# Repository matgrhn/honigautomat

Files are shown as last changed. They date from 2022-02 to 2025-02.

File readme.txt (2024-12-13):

what do you have to check and configure in the arduino sketch:

Please check & update before you upload the sketch to your arduino.
youtube channel containing a set of videos about this vendor machine:
https://youtube.com/playlist?list=PLrYKRosgwf_19UN1uPkxFnaKNIluaASAk

#********************************************************************************#
are you interested in cashless payment (credit card or apple pay etc.) or 
in payment with bill (Zahlung mit Geldscheinen)? Please send a mail.
honigautmat@gmx.de
#********************************************************************************#

#################################################################################
Depending on selected board (e.g. UNO or Mega 2560) and number of buttons=selector and compartments the pin definition must be adapted as follows.
Please ensure that the cable connectors are established accordingly.
//uno
//const int selector[5] = {17, 16, 15, 14, 0 }; // input pins for selector buttons (A0=14, A1=15, A2=16, A3=17, Dig0=0) UNO
// when you want to user 2 * 5 compartments with UNO it is not possible to have power-off features at the same time because of lack of pins. In this case I suggest
// to run 1 row with 5 and one row with 4 compartements; use the free PIN to steer the power off relais; as an alternative you can consider to use PIN 1 (which is not recommended because of issues with serial-IOs); this may be possible 
// if you set all lines dealing with "Serial..." to "// serial..."
//mega
//const int selector[15] = {A1, A2, A3, A4, A5, A6, A7, A8, A9, A10, A11, A12, A13, A14, A15}; // input pins for selector buttons MEGA
const int selector[5] = {A1, A2, A3, A4, A5}; // input pins for selector buttons MEGA 5 buttons and 5/10 or 15 boxes

for Uno with 5 compartments you can use more features than  having 10 compartments; 
to activate search for "refillbutton", "homematic" and "poweroff"; remove "//" in these areas

##################################################################################
Following row defines the price for each compartment. In this example it is 5€; Having 5 Buttons at the vendor machine even with 10 or 15 compartments the number of price is fix: 5
In dieser Zeile kann man vorgeben, welcher Preis für die Fächer vorbelegt werden soll (in diesem Beispiel 5€; es müssen immmer 5 Werte sein, auch wenn man 10 Fächer hat):

int conveyorPrice[5] = {500, 500, 500, 500, 500}; // default 500ct (eeprom currently not used)

How many compartments/rows are available?
Wieviele Fächer je Reihe werden angeschlossen? 

bei 5 Fächern / 5 compartments:
int conveyorItems[5] = {1, 1, 1, 1, 1};
const int maxrow = 1;
const int max = 5; 
int conveyorPrice[5] = {500, 500, 500, 500, 500}; // default value in ct

bei 10 Fächern / 10 compartments:
int conveyorItems[5] = {2, 2, 2, 2, 2};
const int maxrow = 2;
const int max = 5; 
int conveyorPrice[5] = {500, 500, 500, 500, 500}; // default value in ct

bei 15 Fächern / 15 compartments:
int conveyorItems[5] = {3, 3, 3, 3, 3};
const int maxrow = 3;
const int max = 5; 
int conveyorPrice[5] = {500, 500, 500, 500, 500}; // default value in ct

If you want to run the system with a button for each compartment number of rows should be set to 1
##################################################################################
release 3

please consider that for UNO the pin assignment is now different than before!
**********************************************************************************
new feature with release 3 - for UNO 
check temperature with help of DS18B20 and turn cooling on/off 
the usage is recommended in summer time (this feauture is on and power-save disabled when you connect pin "summer_pin" to GND).
for winter disconnect this again.

Temperature sensor DS18B20
RED +5V
BLACK GND (5V)
YELLOW connect to pin "tempsensor" and via 4.7k ohm resistor with +5V

##################################################################################
NV10 - payment with bill now available for Mega 2560

DIPs on NV10:
1 LOW
2 HIGH (this has been changed recently!)
3 LOW
4 HIGH

DIP2 on HIGH to get 4 pulses instead of 1 because in some installations compartment opening impacted the pulse interrupt. Now all pulses less 4 are ignored.

please note that electronic payment with Najax Onyx is not yet ready but dev started! (beta)

int nv10_act = 13;
connect this pin to GND to activate feature

int nv10_ch1 = 9;   
int nv10_ch2 = 10;
connect to PIN 5 + 6 of NV10 to allow 5€ / 10€ (steering via sketch)

NV10 PINs:
1 connect to interrupt pin (arduino) and via 10kOhm to +5V
5 see above
6 see above
15 +12V (better turn on/off via coin acceptor relais "coin power") 
16 GND 12V

##################################################################################
new feature with release 2 - powersave:
after reaching idlePeriod relais "poweroffrelais" cuts the power; wakeup with poweron button (you need a separate self holding relais to keep power). See fritzing-documentation
This feature is active if powersave is set = 1 (otherwhise 0);
##################################################################################
new feature with release 2 - write/read eeprom
current price and remaining products in compartments per button-column will be stored in eeprom and is available after system restart. 
existing credit is deleted when restarting system
To force an eeprom update in case of new structure (e.g. additional set compartments to be activated)
##################################################################################
new feature with release 2 - reset credit after cutofftime = idle threshold
remaining credit will be deleted after a while
##################################################################################
new feature with release 3 - Jan 2023:
it is possible to disable the coin acceptor when all products are sold out
(mega only): connect PIN 17 with a free relais and lead power +12 for coin acceptor
through this relais (function not yet visible in fritzing drawing)

NV10 - bill acceptor now supported / der Geldscheinleser NV10 wird jetzt unterstützt

Payment cashless with Nayax Onyx (you need additional hardware and a contract with
Nayax for reconciliation/bank accounting; monthly fee & percentage to be paid.
Zahlung per Kreditkarte mit Nayax Onyx (in Testphase) wird jetzt unterstützt. 
Dafür wird zusätzliche Hardware sowie ein Supportvertrag mit Nayax benötigt. Dafür
fallen (geringe) monatliche Gebühren sowie ein paar Prozente Abschlag bei Zahlung 
an. Bei Interesse bitte mit mir Kontakt aufnehmen.

#********************************************************************************#

new feature in Oct 2023:

Payment with Nayax Onyx possible now. Please consider that because of the long boot time
of Onyx powersave must be disabled. 
How to wire: +12V, GND, Pulse 1, don't forget to pullup this to +5v;
To use Onyx you need beside the hardware (Onyx and Pulse-cable) an contract with Nayax for
credit card / payment clearing; this leads to an monthly fee and a percentage disagio for each
payment.
#********************************************************************************#

new feature in April 2024:
It is now possible to send & receive SMS-messages. 
You can receive messages about sold items or empty system. You can send messages to
change the threshold for this. You can send messages to load money onto the system and
finally it can be used for paypal-payments (QR-code or your paypal-account should be
visible for the client).
How does it work?
Deactivate the PIN of your simcard. I wasn't able to work with SMS using an IOT-Sim 
because my mobile phone provider doesn't deliver SMS from SIMs with international
phone number (not start e.g. with 49 for germany).
The automat sends a sms when automat is empty (threshold=0), 3 or less remaining 
(threshold=3) or for any sold item (threshold=99). You can send an SMS to your
system e.g. threshold=0 when you want to change the behaviour until the system is restarted.
Then the parameter which is set in the sketch is active again. 

!! don't use the powersupport from ardunino for the sim800L, it consumes too much power!!
Use a separate LM2596 and set this to 3,6V to supply SIM800L (never more than 4,2V)!!

It is now possible to pay with paypal. You have to avtivate "info via mail (html)" on paypal.com
website to receive an email about any received payment. With your email provider
you have to setup SMS-info towards your sim. Then the arduino will indentify how much
money was send and loads it onto the system. The value is visible on the display. It is 
possible to mix cash with paypal if the client wants it.
Preconfigered is any value to be loaded onto the system. Inform you clients
that Paypal-Payments need up to 30 seconds. You can create a QR-Code with a specific
amount of money using your paypal-app. During testing don't cancel your test sendings, because
Paypal blocked my first account and was not willing to reactivate. 
All activities are on your own risk!
Additional benefit: you can load money as well onto the system with sending an SMS containing 
the phrase "Sie haben x,00 EUR erhalten" in case of client is calling you because of 
whatever reason and you may want to give a free product or discount.
Because of this feature you should keep the phone number of your system confidentual.
#*********************************************************************************
Update 11.04.2024:
Nayax Onyx can now be inform about cash payments. I decided not to send the amount of
money by sending a number of pulses back but to send only one pulse (shown in 
nayax app as 1 EUR because number of empty compartments is more important than the
revenue. In configuration (nayax app or my.nayax.com in area "Pulse" set "Pulse IN1 Counter to 1" 
to allow your Nayax Onyx device to receive infos about cash payments. Please be patient, 
it needs some time until the cash payment is visible in you nayax app.
Special case: if a client combines Onyx and cash the last payment done will be used
to decide of a sold item will be reported as cash or not.
 
In addition you can now send "refill" via sms to the machine to activate the refill
routine wihtout opening the machine: all compartments which are registered as empty
will open and counters are set back to value written in the code.

If you have some of the additional hardware components e.g. NV10, Onyx, Sim800L please
use power supply with 2A. 

Update 16.05.2024:
to get Paypal payments we need to receive a SMS containing some key information.
As far as I found out a private Paypal account can be configured at the paypal
website to send sms after receiving money, for a business account you need to set 
up sms info with your mail provider, e.g. gmx is supporting this (9ct costs per sms). 
In the youtube video I show both ways how to setup the paypal. 
The QR code (containing a specific sum) can be generated using the paypal app.

##################################################################################
new feature with release 3 May 2024
with help of ChatGPT I have added some code to support a keypad to select number of
compartment items instead of pushing buttons. This mean all functions depending on buttons
will now be supported by numbers of the keypad e.g. in programming mode
1 - less
2 - more
3 - next
4 - open compartment 
5 - refill
(open and refill only during 'number of items change' phase - not while amending the prices.
it is possible to press one or two number values leading to numbers 0-9 or above 10.
Numbers less or equal "max * maxrow" are accepted during product selection.

###################################################################################

-------------------------------------------------------------------------------
Update 22.06.2024:
SMS:
some SIM800L modules are requesting higher voltage for stable connections - you should increase voltage from 3.6V up to 4.1v (MAX!!) 

Paypal:
depending on Paypal-account, private users can receive SMS directly, business accounts are receiving emails which have to be forwarded by your mail provider as sms.
SMS text contained for me always two spaces in front of text "EUR", but others (e.g. a friend in Austria) are receiving sms containing only one space " EUR". This is now considered in latest sketch (June 2024).
-------------------------------------------------------------------------------
Update 30.09.2024:
SMS/Paypal:
I was informed that Paypal recently changed the SMS message about payments (for private accounts, at least in Austria it was reported).
old text "... Sie haben 7,00 EUR erhalten" or "... Sie haben 7,00  EUR erhalten"  (one or two spaces before "EUR") to
new text "... Sie haben 7.0 EUR erhalten", which means new separator point instead of comma and only one digit after the separator. The sketch is now able to handle all three cases.
Update 0.10.2024:
In addition, the text "..EUR mit PayPal gesendet.." is now validated correctly.

--------------------------------------------------------------------------------
Update 10.10.2024:
Regarding Paypal: sim800l is required for this. Depending on your Paypal account, Paypal sends an SMS (to the number of the machine, which is therefore kept secret), or you receive an email, which you forward to the machine as an SMS via your email account. The Arduino evaluates the text and can then top up a sum. It can take up to 30 seconds for the SMS to arrive at the machine, which is due to Paypal or the email forwarding and not the Arduino.
Attention: Paypal has already blocked two of my accounts due to alleged fraudulent activities, which is why I no longer want to use Paypal. Technically, however, the concept is still supported. However, I now like to use top-up via SMS independently of Paypal by sending the machine an SMS with the appropriate text. One use case is when I get a call from a customer who is standing directly at the machine (coin doesn't work, no change, discount...)
--------------------------------------------------------------------------------
New from October 2024 (release 4):
Please don't use arduino Uno anymore, instead Mega 2560 ist suggested. The sketch is not updated for UNO any more!

Instead of the selection buttons, a keypad (3x4) can now be used. To do this,
keypad = true;
must be set, as well as maxrow=1; because each compartment has its own number with its own price. In programming mode, only prices are set, not product quantities. Input in cents, up to four digits. The price 9.99 is not possible for technical reasons. Every price change is concluded with #.
In programming mode, the compartment can be opened with *, but the counter is not changed. Therefore, always use the refill button when filling empty compartments. If necessary, press any compartments that have been opened incorrectly again afterwards. If prices are to be changed and the associated compartments are to be opened, programming mode must be run through for all compartments twice.
Either selection buttons OR keypad. Both at the same time are not supported.
Update 15.10.2024:
sms process changed. In case of threshold=3 (default or set per sms) the information about available remaining products is only send out in case of exact 3 remaining products and when empty.
Refill will not lead to send sms any more. Please note that threshold is set to value as defined in sketch during refill. 
--------------------------------------------------------------------------------
New from December 2024 
payment with QR-Code from Sumup is now possible!
You need sms feature (see video concerning sim800l / setup sim=true, sim of course, email account for each vending machine - I suggest gmx because it supports sms service [9ct per sms] with free mail account; create an sumup account, create an team member for each vending machine; setup team member and login with as this team member, create payment link , set permanent link = true and notify me about payments to true; generate QR code and add a text hint that it needs about one minute until the payment is displayed on the vending machine.
Login at gmx with specific mail account and create two filter rule: forward mails send from sumup and subject "Sie wurden bezahlt" - don't forget to set the "and"-condition to ensure that both filter rules are true - send sms. Done.
--------------------------------------------------------------------------------

any questions? pls contact me: mailto:honigautomat@gmx.de
Bei Fragen helfe ich gern weiter: honigautomat@gmx.de

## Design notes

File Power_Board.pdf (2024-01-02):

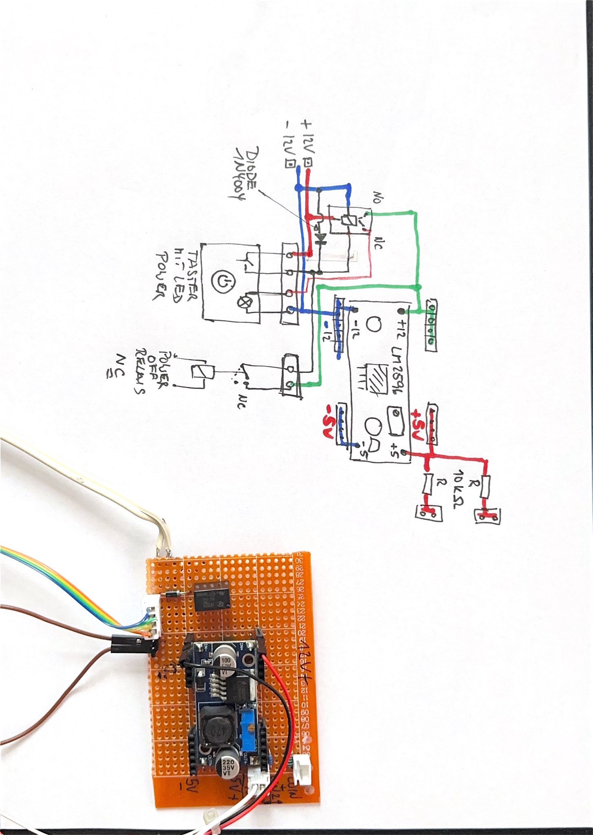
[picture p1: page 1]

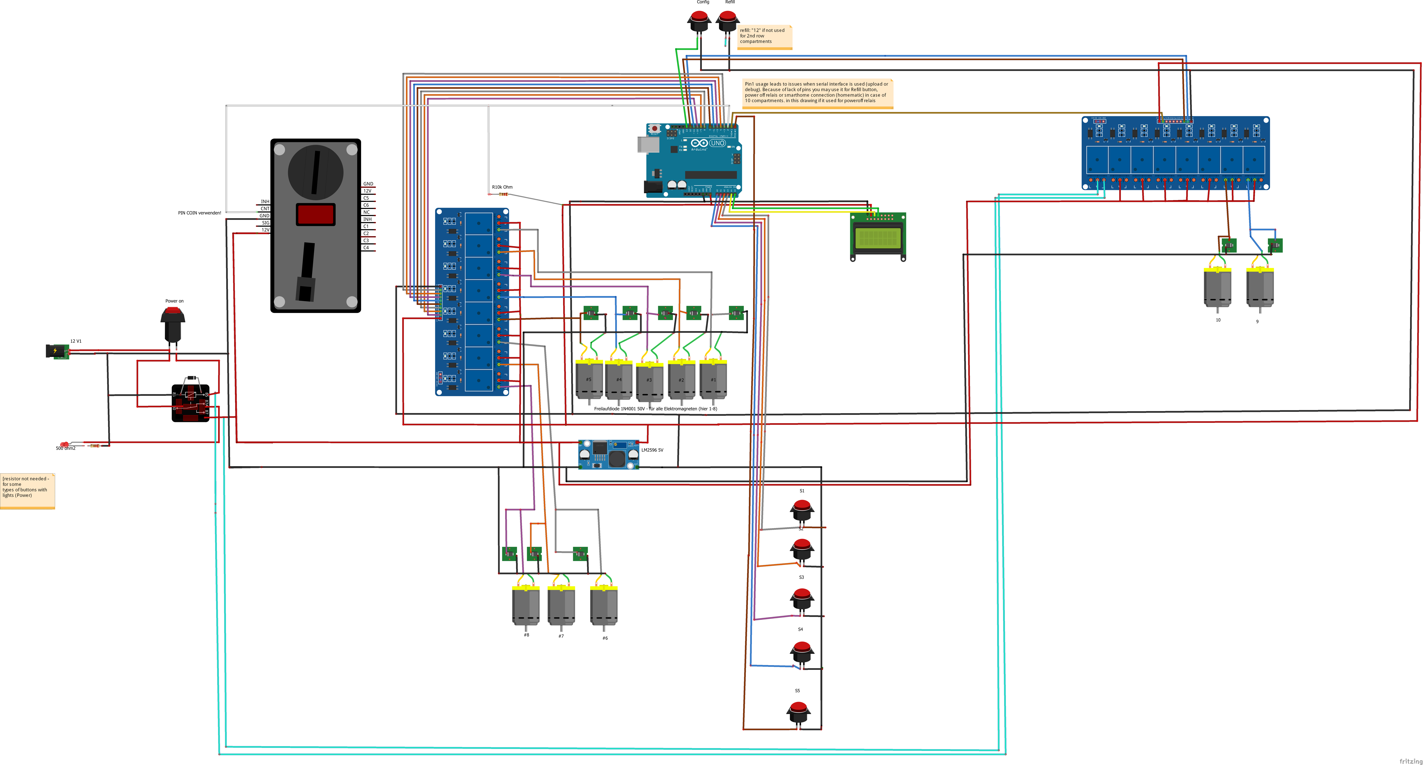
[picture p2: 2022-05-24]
Honigautomat_unoPowersave.png

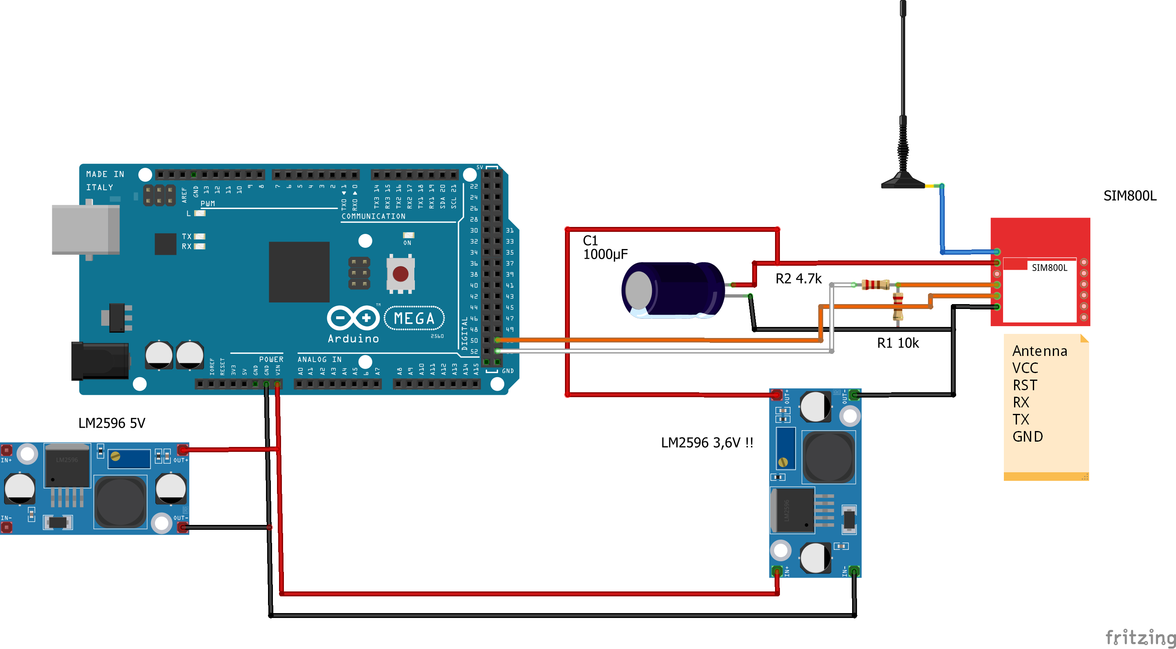
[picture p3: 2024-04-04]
Mega_SIM800l_SMS.png

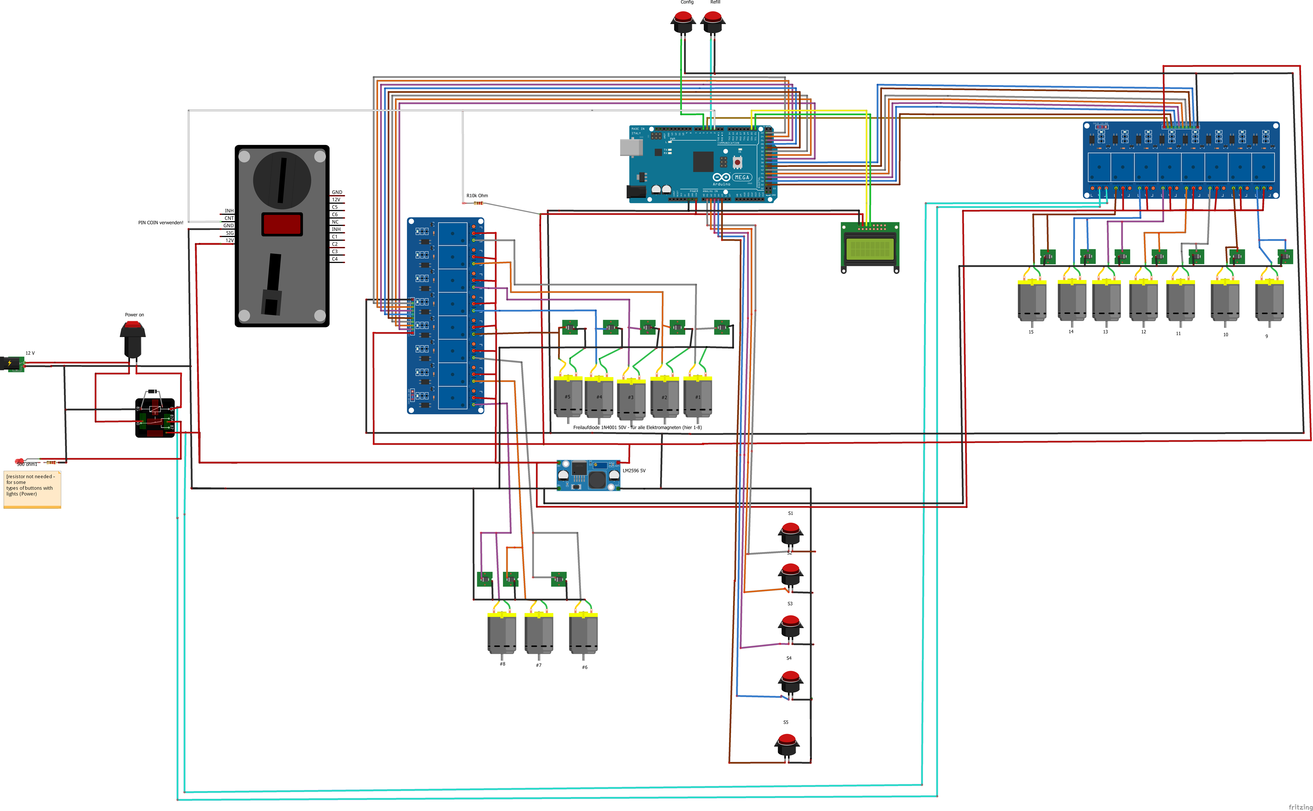
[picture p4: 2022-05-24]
Honigautomat_megaPowersave.png

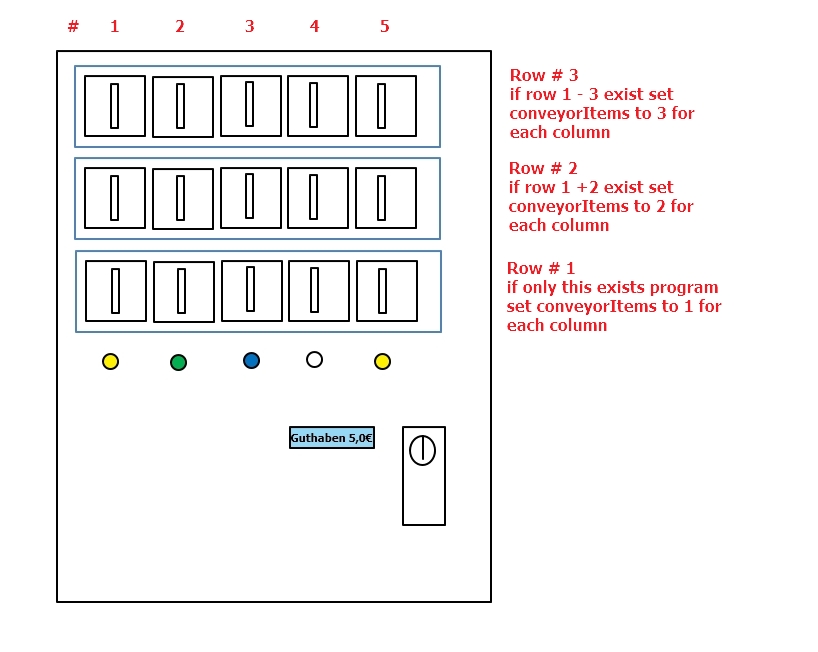
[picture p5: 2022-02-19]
vendor.jpg

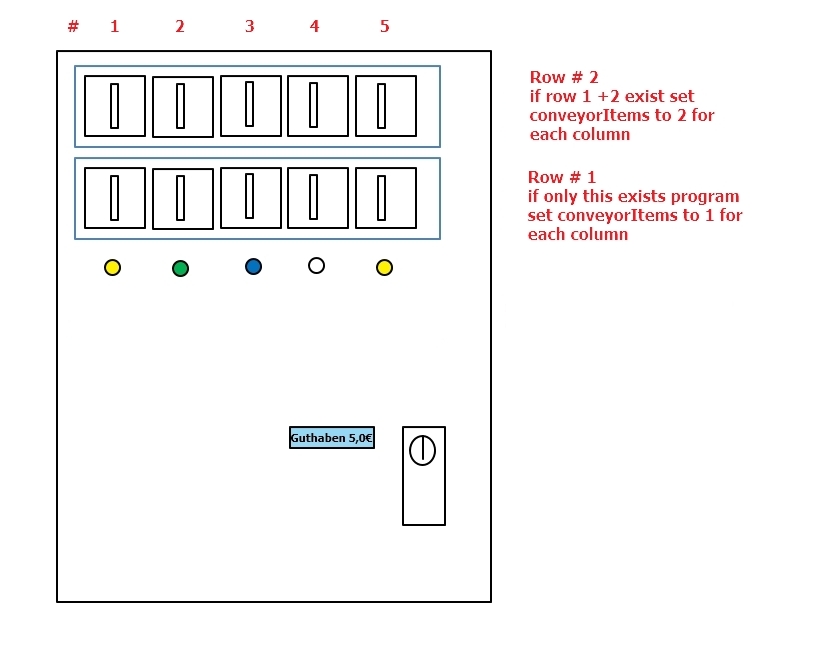
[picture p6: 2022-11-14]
vendor10boxes.jpg

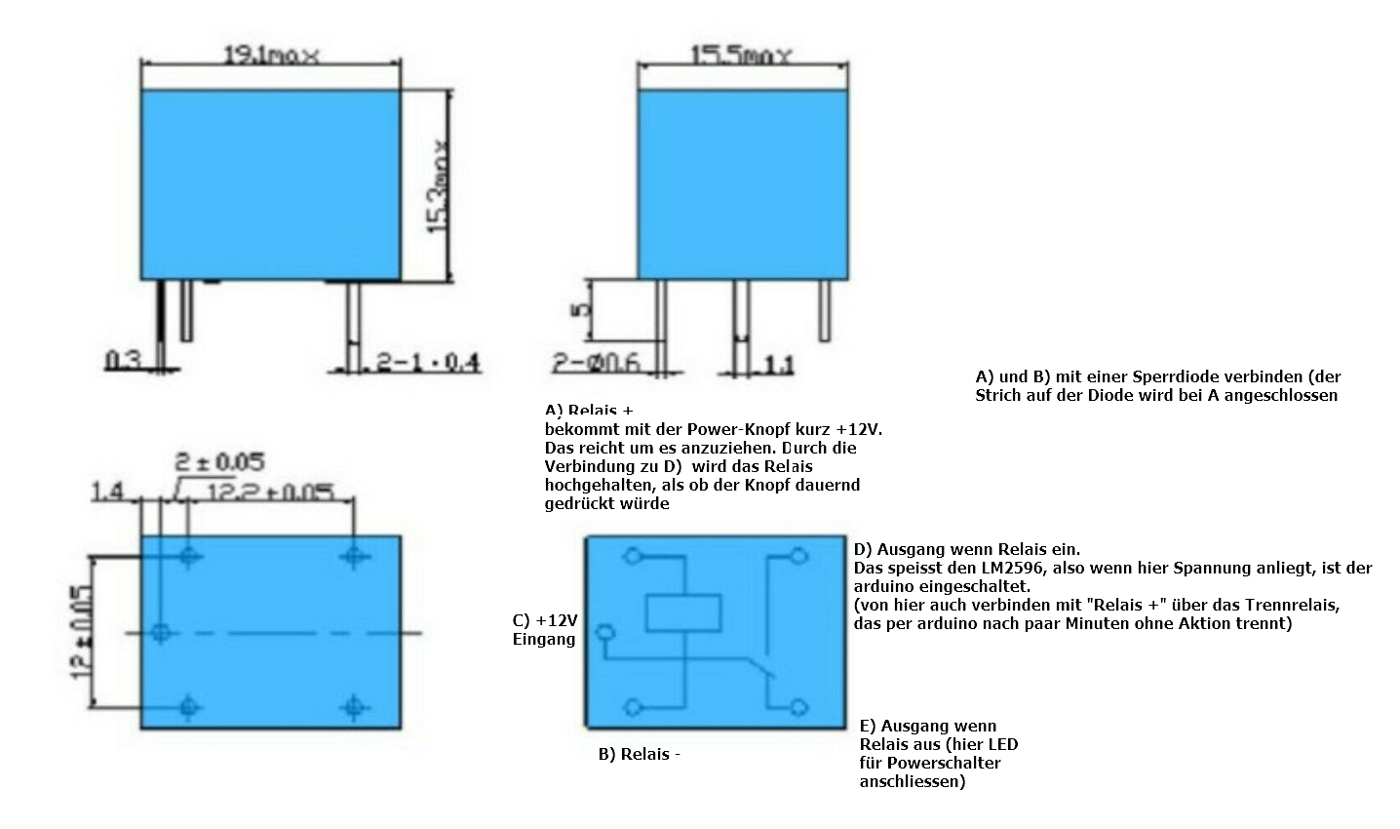
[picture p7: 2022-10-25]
SchaltinfoPowersaveRelais.png

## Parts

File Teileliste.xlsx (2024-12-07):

Bezeichnung | Verkäufer | Anzahl | € pro Stück | Versand | Gesamt | 295.92 €
Netzteil 12V / 1000mA | https://www.ebay.de/sch/i.html?_from=R40&_nkw=netzteil+12v+2a&_sacat=92074&_odkw=netzteil+12v&_osacat=0 | 1 | 8.08 € | 0.00 € | 8.08
Diode 400V / Gesamt 20 Stück | https://www.ebay.de/sch/i.html?_from=R40&_nkw=Diode+1N4004+400V&_sacat=92074&_odkw=diode+1n+4004&_osacat=92074 | 1 | 2.99 € | 0.00 € | 2.99
Münzprüfer 6 Münzen | https://www.ebay.de/sch/i.html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 | 1 | 21.20 € | 0.99 € | 21.20
Arduino | https://www.ebay.de/sch/i.html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 | 1 | 26.95 € | 0.00 € | 26.95
Adapter Display | https://www.az-delivery.de/pages/search-results-page?q=lcd%20display%2016x2%20i2c | 1 | 2.00 € | 0.00 € | 2.00
LCD Display | https://www.az-delivery.de/pages/search-results-page?q=lcd%20display%2016x2 | 1 | 2.50 € | 0.00 € | 2.50
Relais | https://www.az-delivery.de/products/16-relais-modul | 1 | 5.00 € | 0.00 € | 5.00
Magazin | https://www.hornbach.de/p/klarsichtmagazin-5-fach-600-mm-grau-multistore/8831612/ | 1 | 15.95 € | 0.00 € | 15.95
Drucktaster (5v / 16 mm) | https://www.ebay.de/sch/i.html?_from=R40&_nkw=Drucktaster+Schalter+Button+12v+16mm&_sacat=0 | 5 | 7.29 € | 0.00 € | 36.45
Power On (12v / 16mm) TASTER (nicht permanent) | https://www.ebay.de/itm/184891176473 | 1 | 7.29 € | 0.00 € | 7.29
Kabel | https://www.amazon.de/gp/product/B01BI1G88C/ref=ox_sc_act_image_4?smid=A12WNK25ZOTW2F&psc=1 | 1 | 13.27 € | 0.00 € | 13.27
Magnetschlösser | https://www.amazon.de/YoBuyBuy-Elektromagnetschloss-T%C3%BCrzugangskontrolle-Schrankschublade-Elektromagnetisches/dp/B09LSF4NJJ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 | 5 | 5.79 € | 0.00 € | 28.95
10 k Ohm Widerstand |  |  |  |  | 2.00
Platine / Breadboard 5x7 cm 1.6 mm | es geht auch ohne, dann eine leere Platine empfohlen |  |  |  |  | 2.79
DC DC down - Spannungswandler LM2596s |  |  |  |  | 2.00
Verriegelungsschloss | https://www.hornbach.de/shop/Zylinder-Aufschraubschloss-unterschiedlich-schliessend-Tuerstaerke-max-16-mm-Stahl-vernickelt/10208821/artikel.html | 1 |  |  | 9.95
Klavierband 600 mm / 20mm | https://www.hornbach.de/shop/Stangenscharnier-H-600-x-B-20-mm-vermessingt-1-Stueck/5651962/artikel.html |  |  |  | 3.15
Magnetschnäpper | https://www.hornbach.de/shop/Magnetschnaepper-weiss-3-4-kg-4-Stueck/5651822/artikel.html |  |  |  | 3.50
 | Siebdrucksperrholz Sieb/Film 4 mm (https://www.hornbach.de/shop/article/articleLink.html?articleNo=5194437) | 1 ST | 3.53 €
 | Rückwand
 | Länge : 618 mm |  |  |  | 3.53 | 4.88
 | Breite : 435 mm
 | 3,53 € / ST
 | Siebdrucksperrholz Sieb/Film 9 mm (https://www.hornbach.de/shop/article/articleLink.html?articleNo=5194437) | 1 ST | 6.00 €
 | Vorderklappe
 | Länge : 618 mm
 | Breite : 283 mm |  |  |  | 6.00 | 7.26
 | https://www.hornbach.de/shop/Siebdrucksperrholz-Eucalyptus-Sieb-Film-1250x2500x9-mm/10578450/artikel.html
 | Eucalyptus: 9,40€
 | Siebdrucksperrholz Sieb/Film 9 mm (https://www.hornbach.de/shop/article/articleLink.html?articleNo=6504526) | 2 ST | 6.28 €
 | Boden & Deckel |  |  |  | 6.28 | 9.72
 | Länge : 618 mm
 | Breite : 190 mm
 | Eucalyptus: 6,28€
 | 3,14 € / ST
 | Siebdrucksperrholz Sieb/Film 9 mm (https://www.hornbach.de/shop/article/articleLink.html?articleNo=6504526) | 3 ST | 2.16 €
 | Seitenverstärkung & Mitte |  |  |  | 2.16 | 3.36
 | Länge : 270 mm
 | Breite : 100 mm
 | Mitte: Länge: 268 / Seitenteile: 278mm
 | Eucalyptus: 4,50
 | 0,72 € / ST
 | Siebdrucksperrholz Sieb/Film 9 mm (https://www.hornbach.de/shop/article/articleLink.html?articleNo=6504526) | 2 ST | 4.34 €
 | Seitenteile |  |  |  | 4.34 | 6.72
 | Länge : 435 mm
 | Breite : 186 mm
 | 2,17 € / ST
 | Siebdruck 9 mm
 | Halteplatte für Schlösser |  |  |  | 2.00
 | Länge 600 | 1
 | Breite 80mm
 | Bestellbreite 100mm (Mindestmaas)
 | Halteplatte Elektronik Siebdruck 9mm |  | 3.38
 | 190
 | 330
 | https://www.hornbach.de/shop/Siebdrucksperrholz-Eucalyptus-Sieb-Film-1250x2500x9-mm/10578450/artikel.html
************************** | ****************************** | ******* | ******************
Extrareihe Fächer
 | 2 x Bodenplatte
 | Länge : 618 mm
 | Breite : 190 mm
 | Seitenteile 9mm Siebdruck
 | 167* 186 (bei Bestellung muss ein Mass grösser sein, deshalb einmal 338 (davon werden 4 mm durch Sägen weniger) * 186)
 | 338 * 186
 | Rueckwand 4mm
 | 618 * 163
Solar | Amazon
 | 10 A Laderegler |  | 9.49
 | Akku /9Ah, 12V |  | 25.99
 | Solarpanel 30 W |  | 39.90
 | Stecker, Kabel |  | 5.00 |  | 80.38
Keypad | bei Nutzung vom Keypad werden die externen Knöpfe nicht mehr genutzt - man benötigt also nur noch die internen (Prog & Refill) sowie den externen Einschalttaster, sofern man Powersave nutzt

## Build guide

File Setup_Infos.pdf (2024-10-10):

Hier die Playlist bei yt:

https://youtube.com/playlist?list=PLrYKRosgwf_19UN1uPkxFnaKNIluaASAk

Die Anzahl der Auswahlknöpfe bzw. Fächer (Compartments) definiert, was hier geändert werden muss:

const int maxrow = 1; // die Anzahl der Zeilen/Fächer, die alle mit demselben Knopf bedient werden

const int max = 5; // das ist die Anzahl der Spalten (soviele verschiene Preise wären möglich)

neu ab Oktober 2024:

Anstelle der Auswahlknöpfe kann nun ein Keypad (3x4) verwendet werden. Dazu muss

keypad = true;

gesetzt werden, sowie maxrow=1; denn jedes Fach hat eine eigene Nummer mit einem eigenem Preis. Im Programmiermodus werden deshalb nur noch Preise gesetzt, keine Produktanzahlen. Eingabe in Ct, bis zu vier Stellen. Der Preis 9,99 ist aus technischen Gründen nicht möglich. Jedes Preisänderung wird mit # abgeschlossen.

Im Programmiemodus kann mit * das Fach geöffnet werden, dabei wird er Zähler nicht geändert. Deshalb beim Auffüllen leerer Fächer immer den Refillknopf nutzen. Ggfs. falsch geöffnete Fächer im Anschluss wieder zudrücken. Wenn Preise geändert werden und auch dazu gehörende Fächer geöffnet werden sollen, ist der Programmiermodus für alle Fächer zwei zu durchlaufen.

Entweder Auswahlknöpfe ODER Keypad. Beides gleichzeitig wird nicht unterstützt.

Für den Modus Auswahlknöpfe, also ohne Keypad:

Button | 1 | 2 | 3 | 4 | 5
Preis | 5€ | 5€ | 6€ | 7€ | 8€
Fach (Zeile 1) | F | F | F | F | F
Fach (Zeile 2) | F | F | F | F | F
Fach (Zeile 3) | F | F | F | F | F

Bei diesem Beispiel sind es 5 Spalten (max=5) und drei Reihen (maxrow=3)

Dazu passend müssen die Pins bzw. Speicher definiert (I für Knöpfe, II für die Schlösser (werden per Relais geöffnet) III für die Anzahl der vorhandenen Produkte, IV die Preise) werden, z.B. in diesem Beispiel sind es 15 Fächer, also:

I )

const int selector[15] = {A1, A2, A3, A4, A5, A6, A7, A8, A9, A10, A11, A12, A13, A14, A15}; // input pins for selector buttons MEGA

II)

const int relays[15] = {22,24,26,28,30,32,34,36,38,40,42,44,46,48,50}; // mega: 15 boxes

Das sind die Pins für 15 Schlösser

III)

int conveyorItems[5] = {3, 3, 3, 3, 3};

Hier sind es 5 Spalten mit je 3 Fächern.

IV) Dann noch die Tabelle für die Preise:

int conveyorPrice[5] = {500, 500, 600, 700, 800};

Bitte achte darauf, dass die Kabel auf die richtigen Pins am Arduino gesteckt werden.

============================================================================

Ein anderes Beispiel:

Button | 1 | 2 | 3 | 4 | 5
Preis | 5€ | 5€ | 5€ | 5€ | 7€
Fach (Zeile 1) | F | F | F | F | F

bei 5 Fächern / 5 compartments:

I)

const int selector[5] = {A1, A2, A3, A4, A5 }; // input pins for selector

II)

const int relays[5] = {3, 4, 5, 6, 7};

III)

int conveyorItems[5] = {1, 1, 1, 1, 1};

IV)

int conveyorPrice[5] = {500, 500, 500, 500, 700};

const int maxrow = 1;

const int max = 5;

Wenn man für jedes Fach einen eigenen Knopf haben will, ist maxrow = 1; zu setzen

Achtung: wenn man eine neue Version auf den Arduino spielt, bei der sich die Anzahl der Knöpfe, Fächer, Zeilen oder so geändert hat, muss

const int EEPROM_version = 1;

geändert werden (einfach hochzählen), damit die Werte im EEPROM überschrieben werden

NV10 - payment with bill now available for Mega 2560

DIPs on NV10:

1 LOW

2 HIGH (this has been changed recently!)

3 LOW

4 HIGH

DIP2 on HIGH to get 4 pulses instead of 1 because in some installations compartment opening impacted the pulse interrupt. Now all pulses less 4 are ignored.

int nv10_act = 13;

connect this pin to GND to activate feature

int nv10_ch1 = 9;

int nv10_ch2 = 10;

connect to PIN 5 + 6 of NV10 to allow 5€ / 10€ (steering via sketch)

NV10 PINs:

1 connect to interrupt pin (arduino) and via 10kOhm to +5V

5 see above, Pin9

6 see above, Pin10

14 GND 12V

15 +12V (better turn on/off via coin acceptor relais "coin power")

new feature with release 2 - powersave:

after reaching idlePeriod relais "poweroffrelais" cuts the power; wakeup with poweron button (you need a separate self holding relais to keep power). See fritzing-documentation

This feature is active if powersave is set = 1 (otherwhise 0);

new feature with release 3 - Jan 2023:

it is possible to disable the coin acceptor when all products are sold out

(mega only): connect PIN 17 with a free relais and lead power +12 for coin acceptor through this relais (function not yet visible in fritzing drawing)

NV10 - bill acceptor now supported / der Geldscheinleser NV10 wird jetzt unterstützt

Payment cashless with Nayax Onyx (you need additional hardware and a contract with

Nayax for reconciliation/bank accounting; monthly fee & percentage to be paid.

Zahlung per Kreditkarte mit Nayax Onyx wird jetzt unterstützt.

Dafür wird zusätzliche Hardware sowie ein Supportvertrag mit Nayax benötigt. Dafür

fallen (geringe) monatliche Gebühren sowie ein paar Prozente Abschlag bei Zahlung

an. Bei Interesse bitte mit mir Kontakt aufnehmen.

#********************************************************************************#

new feature in Oct 2023:

Payment with Nayax Onyx possible now. Please consider that because of the long boot time

of Onyx powersave must be disabled.

How to wire: +12V, GND, Pulse 1, don't forget to pullup this to +5v;

To use Onyx you need beside the hardware (Onyx and Pulse-cable) an contract with Nayax for

credit card / payment clearing; this leads to an monthly fee and a percentage disagio for each

payment.

#********************************************************************************#

Zu Paypal: dafür ist sim800l notwendig. Je nach Paypalaccount sendet Paypal eine SMS (an die Nummer des Automaten, die man deshalb geheim hält), alternativ erhält man eine Email, die man über seinen Mailaccount als SMS an den Automaten weiterleitet. Der Arduino wertet den Text aus und kann dann eine Summe aufladen. Bis die SMS am Automaten ankommt, kann es bis zu 30 Sekunden dauern, was an Paypal bzw. der Mailweiterleitung liegt und nicht am Arduino.

Achtung: Paypal hat mir schon zwei Accounts wegen angeblich betrügerischer Aktivitäten gesperrt, weshalb ich Paypal nicht mehr nutzen möchte. Technisch ist das Konzept aber noch weiter unterstützt. Ich nutze das Aufladen per SMS aber inzwischen gern unahbhängig von Paypal indem ich dem Automaten eine SMS mit dem passenden Text schicke. Ein Anwendungsfall ist, wenn ich von einem Kunden angerufen werde, sofern er direkt am Automaten steht (Münze funktioniert nicht, kein Wechselgeld, Rabatt..)

any questions? pls contact me: mailto:honigautomat@gmx.de

Bei Fragen helfe ich gern weiter: honigautomat@gmx.de

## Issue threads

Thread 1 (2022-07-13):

Librarie update

steve-1000, 2022-07-13:
Möchte den Code gerne auf einem Arduino Nano every nutzen - sollte sogar voll kompatibel sein?!
folgend Vorschläge hätte ich:

aufgrund von Fehlermeldungen beim kompilieren:
die Librarie LCD.h war nicht out of the Box in meiner Arduino ide Vers. 1.8.19 verfügbar.
Konnte diese dann hier runterladen:https://github.com/jenschr/Arduino-libraries/tree/master/LiquidCrystal
und manuell in "C:\Program Files (x86)\Arduino\libraries" (Windows10) hinzufügen.
evtl. gibt es da was aktuelleres was diese manuelle Anpassung überflüssig macht?

Punkt 2: in der lcd.h Librarie wird noch die "#include "WProgram.h" verwendet - > ebenfalls nicht mehr aktuell. Die manuellen notwendigen Anpassungen hab ich hier gefunden:
https://forum.arduino.cc/t/wprogram-h-problem-help/499019/4
#include "WProgram.h --> soll demnach in #include <Arduino.h> geändert werden.

Ansonsten: Top Thema und Projekt! Danke fürs teilen!!

matgrhn, 2022-07-13:
Hallo Joshuad,
stimmt, du brauchst die Bibliothek für dad LCD Display, z.B. https://www.dropbox.com/s/h7psvzjazhsivgu/newLiquidCrystal.zip?dl=0

diejenige, die du genannt hast, mag auch funktionieren.
Viele Grüße
Matthias

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

Closed 2023-06-13.

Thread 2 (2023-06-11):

Ausverkauft und dann Stopp

theone0one, 2023-06-11:
Ich habe das ganze nun einmal nachgebaut und habe verschiedene Szenarien probiert.
Allerdings fiehl mir auf, dass wenn alle Waren ausverkauft sind kommt ja die Meldung "Ware leer"...
Ich habe es bei mir halt Ausverkauft genannt.
Doof war nur das er nach gewisser Zeit in den Idle Modus ging und die Idle Texte anzeigte.
Wie... "bitte Geld einwerfen" etc...

Ich konnte es nun wie folgt lösen.
Sobald alle Waren verkauft sind spingt er zu der Anzeige "Waare leer" und wartet dort bis der Refill-Button betätigt wurde.

```c++
    lcd.clear();
    lcd.setCursor(0, 0);
    lcd.print("Ausverkauft! ");
    lcd.setCursor(0, 1);
    lcd.print("AUSSER BETRIEB! ");
    delay (5000);
   digitalWrite(coin_relais_pin,LOW);
   pinMode(coin_relais_pin, OUTPUT);
	//--> Warte auf Refill!
	while (digitalRead(refillbutton) == HIGH){

 }
```

Ich hoffe das ist richtig so.

matgrhn, 2023-06-13:
hi,

danke für die Idee – werde ich einarbeiten.

VG
Matthias

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

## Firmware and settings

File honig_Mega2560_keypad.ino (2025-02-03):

#include <Wire.h>
#include <LCD.h>
#include <LiquidCrystal_I2C.h>
#include <EEPROM.h>
#include "SoftwareSerial.h"
#include <Keypad.h>     // Bibliothek für das Keypad
#include <Keypad_I2C.h> // Bibliothek für das Keypad über I2C

#define PIN_TX 51
#define PIN_RX 53
// ######### INIT SIM / SMS #########
// Cell phone number incl. country code "+49" for Germany and xxxxxxxxxxx = phone number
//   don't forget to change your phone number: !!!!!!!!!!!!!!
const char TELEFONE_NUMBER[] = "+xxxxxxxxxxxx"  ;
// 
bool sim = false;
bool refill_ongoing = false;

SoftwareSerial mySerial(PIN_TX, PIN_RX);

// ########## INIT DISPLAY ##########

// LiquidCrystal_I2C lcd(0x27, 2, 1, 0, 4, 5, 6, 7, 3, POSITIVE); // Set the LCD I2C address UNO
LiquidCrystal_I2C lcd(0x27, 2, 1, 0, 4, 5, 6, 7, 3, POSITIVE); // Set the LCD I2C address MEGA2560 ; PIN 20 SDA, PIN 21SCL 
//                 or 0x3F correct? see https://www.youtube.com/watch?v=B8DNokj9LnY


// ############ specific configurations ####################

// max = number of buttons (default: 5; even with 1,2 or 3 rows of 5 compartments); if you want to have a button for each compartment increase up to 15 or more
// don't forget to look at EEPROM structure when changing value of max
const int max = 10; 
// number of rows (1 = 5 compartments, 2 = 10 compartments, 3 = 15 compartments)
// if maxrow <=2 the button #5 is used to start refill programm otherwise for open 3rd row during programming
const int maxrow = 1;

unsigned long idlePeriod = 120000; // time in ms between idle messages or shutdown e.g. 180000  
// powersave = 0 show text when Idle; powersave = 1 shutdown when IdlePeriod reached

// debug modus: if you need 10 vendors and one additonal PIN (TX0 / Digital PIN 1 which should normally not be used) on UNO turn debug mode to 0 which disables serial 
// I use this pin to send a message to my smarthome system for any purchased product
bool debug = true;
 //          if (!debug) {
          const int homematic_pin = 6;   
          const int homematic_pin_empty = 7;
 //          }
unsigned long idleTimerMillis = 0;
int randomNumber = 0;

// ### sms_available_products = 0 to send SMS only when sold out, otherwise 99
// sms_change_thresholds :   "threshold=0", "threshold=3", "threshold=99" (send this via sms, works until restart)
 
int sms_available_products = 3;
int last_available_products = 99;

const int buzzer_pin = 49;


// #### parameter for Paypal or sumup payment (QR-code incl. value to be generated via Paypal mobile app or sumup webpage)
// email forward to sms including following string: 
//const char smsPayPal7       = "Sie haben 7,00 EUR erhalten";
const int  smsPayPal7value  = 700;

// ox cashless payment
bool ox = false;
int ox_credit_per_pulse = 100;
// volatile int ox_coinsCurrentValue = 0;
volatile int ox_difference = 0; 
int ox_Change = 0; // a coin has been inserted flag
unsigned long ox_currentMillis = 0;
unsigned long ox_oldMillis = 0;
volatile int ox_pulsecount = 0;
int ox_inhibit_relais_pin = 11;
int ox_act = 12;


// nv10 cashless payment
// NV10 - payment with bill now available for Mega 2560

// DIPs on NV10:
// 1 LOW
// 2 HIGH (this has been changed recently!)
// 3 LOW
// 4 HIGH
// DIP2 on HIGH to get 4 pulses instead of 1 because in some installations compartment opening impacted the pulse interrupt. Now all pulses less 4 are ignored.
// credit per pulse is now 125 instead of 500

bool nv10 = false;
int nv10_credit_per_pulse = 125;
// volatile int nv10_coinsCurrentValue = 0;
volatile int nv10_difference = 0; 
int nv10_Change = 0; // a coin has been inserted flag
unsigned long nv10_currentMillis = 0;
unsigned long nv10_oldMillis = 0;
volatile int nv10_pulsecount = 0;
int nv10_act = 13;
int nv10_ch1 = 9;
int nv10_ch2 = 10;

char last_paytype = '?';

// ########## keypad usage ##########
// in case of keypad usage: set maxrow = 1 and max to number of vending units!
// it is not possible to use select buttons and keypad in parallel.
// each vending unit can have a specific price
bool keypad = false;
const byte ROWS = 4;  
const byte COLS = 3;   
char keys[ROWS][COLS] = {
  {'1','2','3'},
  {'4','5','6'},
  {'7','8','9'},
  {'*','0','#'}
};

byte rowPins[ROWS] = {0, 1, 2, 3}; // connection to rows of keypads (PCF8574 P0-P3)
byte colPins[COLS] = {4, 5, 6};    // columns (PCF8574 P4-P6)

Keypad_I2C customKeypad(makeKeymap(keys), rowPins, colPins, ROWS, COLS, 0x20); // 0x20 is the I2C Address des PCF8574 (changeable, you find it with help of sketch "i2c_scanner")

unsigned long lastKeyPressTime = 0;
int knumber = 0;
int select = 999;
bool singleDigitEntered = false;
bool doubleDigitEntered = false;
bool tripleDigitEntered = false;

// ########## INIT BUTTONS ##########

//const int selector[5] = {17, 16, 15, 14, 0 }; // input pins for selector buttons (A0=14, A1=15, A2=16, A3=17, Dig0=0) UNO
//const int selector[15] = {A1, A2, A3, A4, A5, A6, A7, A8, A9, A10, A11, A12, A13, A14, A15}; // input pins for selector buttons MEGA
const int selector[15] = {A1, A2, A3, A4, A5, A6, A7, A8, A9, A10, A11, A12, A13, A14, A15}; // input pins for selector buttons MEGA
//const int selector[5] = {A1, A2, A3, A4, A5}; // input pins for selector buttons MEGA 5 buttons and 5/10 or 15 boxes

// ### don't uses dig1 PIN because it is related to the serial monitor and will causes issues with external periphery (UNO)
// PINS
const int configbutton = 5;   // 5 for Mega; 13 for Uno
const int refillbutton = 3;  // 3 for Mega; for Uno 12 (if only one row of compartments exists: maxrow = 1)
const int powersave_relais_pin = 4;  // 4 for Mega; for Uno 11
const int powersave = 0;  // powersave = 1 -> turnoff power after idle threshold; run at least onetime with 0 to ensure correct data on eeprom

// #### EEPROM structure
//  0          -> 1           : version of this structure : 1 
//  2          -> 3           : max = number of buttons
//  4          ->            
//  index * 2 + 4             : conveyorItems []
//  index * 2 + max * 2 + 4   : conveyorPrice []

const int EEPROM_version = 1;
 

// ########## INIT VALUES ##########
// #max
// #PREIS
int conveyorPrice[15] = {700, 700, 700, 700, 700, 700, 700, 700, 700, 700, 700, 700, 700, 700, 700}; // default price  
//int conveyorPrice[5] = {700, 700, 700, 700, 700}; // default price  
int conveyorItems[15] = {1, 1, 1, 1, 1, 1, 1, 1, 1, 1, 1, 1, 1, 1, 1};
//int conveyorItems[5] = {2, 2, 2, 2, 2};

// ########## INIT COIN ACCEPTOR ##########

const int coinInt = 0; // attach coinInt to interrupt pin 0 = digital pin 2 = digitalPinToInterrupt(2) . (interrupt pin 1 = digital pin 3 = digitalPinToInterrupt(3))
const int coin_relais_pin = 17;
// ########## INIT Cashless payment ox interrupt ##############
const int ox_Int = 18; // attach coinInt to interrupt pin 
// ########## INIT bill payment nv10 interrupt ##############
const int nv10_Int = 19; // attach nv10 to interrupt pin 

// set the coinsCurrentValue to a volatile float
// volatile as this variable changes any time the Interrupt is triggered
volatile int coinsCurrentValue = 0;
int coinsChange = 0; // a coin has been inserted flag

unsigned long currentMillis = 0;
unsigned long oldMillis = 0;

int pulsecount;

const unsigned int wt_ms = 100; // wait ms

// const int relaisPin = xx; //
//const int relays[10] = {3, 4, 5, 6, 7, 8, 9, 10 , 11, 12}; //uno: 10 boxes
const int relays[15] = {22,24,26,28,30,32,34,36,38,40,42,44,46,48,50}; // mega: 15 boxes
 

//const int poweroffrelais = 4;  // mega: 4; uno: only possible if less 10 compartments; in this case pin 12 recommended; remove this pin from relais list
// poweroffrelais replaced by powersave_relais_pin
// ########## END OF INIT ##########

// ########## SETUP ###################################################################################

void setup() {



if (debug) {
  Serial.begin(9600); // start serial communication
  Serial.println("Setup gestartet");
  }
 for (int index = 0; index < max; index++) {
   pinMode(selector[index], INPUT_PULLUP);
 }
 
  pinMode(configbutton, INPUT_PULLUP);
  pinMode(refillbutton, INPUT_PULLUP);  
  pulsecount = 0;
  digitalWrite(powersave_relais_pin, HIGH);
  pinMode (powersave_relais_pin, OUTPUT);

  digitalWrite(homematic_pin, HIGH);
  pinMode (homematic_pin, OUTPUT);

  digitalWrite(homematic_pin_empty, HIGH);
  pinMode (homematic_pin_empty, OUTPUT);

  digitalWrite(buzzer_pin, LOW);
  pinMode (buzzer_pin, OUTPUT);

 
   /// #### start coin acceptor & deactivate ox_inhibit
  // payment_on_off ();
      
 // lcd.begin(20, 4); // set up the LCD's number of columns and rows
  lcd.begin(16, 2); // set up the LCD's number of columns and rows
  lcd.print("Bitte warten..."); // Print wait message to the LCD
   if (debug) {
  Serial.println("Warten auf Muenzpruefer");
  }
  delay(500); // don't start main loop until we're sure that the coin selector has started

  lcd.clear();
  lcd.setCursor(0, 0); 

  // if coinInt goes HIGH (a Pulse), call the coinInserted function
  // an attachInterrupt will always trigger, even if your using delays
  //  attachInterrupt(digitalPinToInterrupt(2), coinInserted, RISING);
  attachInterrupt(coinInt, coinInserted, RISING);
   
  pinMode(ox_act, INPUT_PULLUP);
  if (digitalRead(ox_act) == LOW) {ox = true;} else {ox = false;}

if (debug) {
 if (ox) {
    Serial.print(" ox true ");
    }
    else
    {
    Serial.print(" ox false ");
    }
}     

if (ox) {
 ox_oldMillis = millis();
 if (debug) {
      Serial.print(" ox_oldMillis ");
      Serial.print(ox_oldMillis);
 }
 
}

  pinMode(nv10_act, INPUT_PULLUP);
  if (digitalRead(nv10_act) == LOW) {nv10 = true;} else {nv10 = false;}

if (debug) {
 if (nv10) {
    Serial.print(" nv10 true ");
    }
    else
    {
    Serial.print(" nv10 false ");
    }
}   
 
if (nv10) {
 nv10_oldMillis = millis();
 if (debug) {
      Serial.print(" nv10_oldMillis ");
      Serial.print(nv10_oldMillis);
 }
 
}
if (sim)
   {
    lcd.setCursor(0, 1);
  lcd.print("SIM init..10sek "); 
     delay(10000);
   // Serial.begin(9600);
	digitalWrite(buzzer_pin, HIGH); 
  delay(250);
  digitalWrite(buzzer_pin, LOW); 
  
  mySerial.begin(9600);


	Serial.println("Initializing sim..");
  mySerial.println("AT");
  updateSerial(wt_ms);
  Serial.println("AT+CMGF=1");
  mySerial.println("AT+CMGF=1"); // SMS text mode
  updateSerial(wt_ms);  

//## how to handle incoming SMS:
//### display sms
mySerial.println("AT+CNMI=1,2,0,0,0"); // Decides how newly arrived SMS messages should be handled
// save sms
//  mySerial.println("AT+CNMI=2,1,0,0,0"); // Decides how newly arrived SMS messages should be handled
  updateSerial(wt_ms);
  delay(1000);
  

  Serial.println(" AT+CMGL:");
 // mySerial.println("AT+CMGL=\"ALL\"\r"); // show all sms stored in SIM-card
 // updateSerial(wt_ms);
 //Serial.println(" del all sms:");
 //mySerial.println("AT+CMGL=\"DEL ALL\"\r"); // delete all sms from sim-card
 // updateSerial(wt_ms);
 Serial.println(" weiter..");
  updateSerial(wt_ms);
  delay(1000);

  last_available_products = sms_available_products;

   }

  lcd.clear();
  lcd.setCursor(0, 1);
  lcd.print("ox "); 
  lcd.print(ox);  
  lcd.print(" nv10 "); 
  lcd.print(nv10);  
  lcd.print(" sim "); 
  lcd.print(sim);  
  lcd.setCursor(0, 0);
//  lcd.print(" av "); 
 // lcd.print(available_products);  
  lcd.print(" mx "); 
  lcd.print(max);  
  lcd.print(" mxr "); 
  lcd.print(maxrow);  
  delay(3000); 

if (keypad) {
lcd.clear();
  lcd.setCursor(0, 1);
  lcd.print("key "); 
  lcd.print(keypad);  
 if (debug) {
      Serial.print(" keypad active! ");
       }
  customKeypad.begin();
  Wire.begin();
delay(200);
}


// Relais initialisieren

 for (int index = 0; index < (max * maxrow); index++) {
  digitalWrite(relays[index], HIGH); // Turn OFF
  pinMode(relays[index], OUTPUT);
 }

digitalWrite(powersave_relais_pin,HIGH);
 pinMode(powersave_relais_pin, OUTPUT);

 if ((readEEPROM (0) != EEPROM_version) or (readEEPROM (2) != max))
 {
   if (debug) {
    Serial.print("EEPROM_vers ");

    Serial.print (readEEPROM (0)); 
    Serial.print("Emax ");
    Serial.print (readEEPROM (2)); 
    Serial.print("PVer: ");
    Serial.print(EEPROM_version);  
    Serial.print("PrMax: "); 
    Serial.println(max);   
   }    
    lcd.clear();
    lcd.setCursor(0, 0);
    lcd.print("INIT EEPROM ");
    lcd.setCursor(0, 1);    
    lcd.print(" v ");
    lcd.print( EEPROM_version);
  //  lcd.print(" max ");    
  //  lcd.print( max );   
  if (debug) {
      Serial.print("writeEEprom.. ");     
  }      
   writeEEPROMcomplete();
   if (debug) {
    Serial.print("ende IF ");
   }    
 } 
 else
 {
// read EEPROM and update values
if (debug) {
  Serial.println(" else:read EEPROM and upd ");
}  
 readEEPROMcomplete();
   
 }
   
 //delay(200);
coinsCurrentValue = 0;
lcd.print("Guthaben reset");
delay(200);
if (debug) {
  Serial.println("Bereit");
}  
  lcd.clear();
  lcd.print("Bereit.");
 // if coinInt goes HIGH (a Pulse), call the coinInserted function
  // an attachInterrupt will always trigger, even if your using delays
  //  attachInterrupt(digitalPinToInterrupt(2), coinInserted, RISING);
  attachInterrupt(coinInt, coinInserted, RISING);

  payment_on_off ();
}

// ########## COIN INSERT ##########

// This function is called by interrupt every time we receives a pulse from the coin acceptor
void coinInserted() {
coinsChange = 1; // flag that there has been a coin inserted
last_paytype = 'C';


  currentMillis = millis();
  int difference = currentMillis - oldMillis;

//  Serial.print("difference: ");
if (debug) {
  Serial.println(difference); 
}
  oldMillis = currentMillis;
  pulsecount++;

// new coin? start to count from beginning....   
if (difference > 140 or difference < 50 ) {
    if (pulsecount > 1) {
       pulsecount = 1;
     }
   }

if (difference < 141) {
switch (pulsecount) {
case 2: coinsCurrentValue = coinsCurrentValue + 10;  
        break; 
case 3: coinsCurrentValue = coinsCurrentValue + 10;  
        break; 
case 4: coinsCurrentValue = coinsCurrentValue + 30;  
        break; 
case 5: coinsCurrentValue = coinsCurrentValue + 50;  
        break; 
case 6: coinsCurrentValue = coinsCurrentValue + 100;  
        break;         
   } // switch
  } // if
    idleTimerMillis = millis();
if (debug) {    
  Serial.print ("(/coinsInserted)neuer Wert: ");
  Serial.println (  coinsCurrentValue);
  Serial.print("last Paytype: ");
  Serial.println (last_paytype);
}
}


// ########## OX PULSE - cashless payment ##########

// This function is called by interrupt every time we receives a pulse from the coin acceptor
void ox_pulse() {
ox_Change = 1; // flag that there has been cashless payment done
last_paytype = 'O';

ox_pulsecount++;
ox_currentMillis = millis();
 int ox_difference = ox_currentMillis - ox_oldMillis;
     
  ox_oldMillis  = ox_currentMillis; 

if (debug) {    
  Serial.print ("(/ox_pulse) neuer Wert: ");
  Serial.println (  ox_pulsecount);
}
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
void loop() {
  if (digitalRead(configbutton) == LOW) {
if (debug) {
   Serial.print("DigitalRead(configb): LOW");
}
   set_values();
   delay(1000);
  }

 if (digitalRead(refillbutton) == LOW) {
if (debug) {   
   Serial.print("DigitalRead(refillbutton): LOW");
}   
   refill();
 writeEEPROMcomplete(); 
   delay(1000);
  }  
//if (debug) {
//    Serial.print("idle ");
// }    
  idle();

  // check if a coin has been inserted
 if (coinsChange == 1) {
  if (debug) {
    Serial.print("CoinsChange ");
   }    
   coinsChange = 0; // unflag that a coin has been inserted
   idleTimerMillis = millis();
   displayBalance(); // display current balance
  
  }



// check if a bill has been inserted
 if (nv10_Change == 1) {
  if (debug) {
    Serial.print("NV10_Change ");
   }    
   nv10_Change = 0; // unflag that a coin has been inserted
   idleTimerMillis = millis();
   displayBalance(); // display current balance
  
  }

// check if a card or mobile payment has been done
 if (ox_Change == 1) {
  if (debug) {
    Serial.print("ox_Change ");
   }    
   ox_Change = 0; // unflag that a card or mobile payment has been done
   idleTimerMillis = millis();
   displayBalance(); // display current balance
  
  }
 // *********** keypad pressed **********

 if (keypad) {
char key = customKeypad.getKey();
 
  if (key) {
    if (debug) {
    Serial.print("keypad_2 ");
   }    
    unsigned long currentTime = millis();
    digitalWrite(buzzer_pin, HIGH); 
    delay(150);
    digitalWrite(buzzer_pin, LOW); 

    if (singleDigitEntered && (currentTime - lastKeyPressTime <= 1000)) {
      if (debug) {
    Serial.print("keypad_3 ");
   }    
      // second press within short time
       knumber = knumber * 10 + (key - '0');
      singleDigitEntered = false;
      Serial.println(knumber);
    } else {
 
      // first key pressed
      knumber = key - '0';
      singleDigitEntered = true;
      lastKeyPressTime = currentTime;
  if (debug) {
         Serial.print("keypad_4 ");
         Serial.println(knumber);
        } // debug
  } // else
  } // keypad
  

  // last press long time ago...
  if ((singleDigitEntered && (millis() - lastKeyPressTime > 1000))) {
    if (debug) {
    Serial.print("keypad_5 ");
   }    
    singleDigitEntered = false;
    Serial.println(knumber);
    digitalWrite(buzzer_pin, HIGH); 
    delay(100);
    digitalWrite(buzzer_pin, LOW); 
  }
}
// valid keys selected 
  select = 999;
if ((knumber > 0) && (millis() - lastKeyPressTime > 1000) and (knumber <= (max * maxrow)))
{
 if (debug)
  {
  Serial.println("valid keypad entry! ");
  Serial.println("knumber: ");
  Serial.println(knumber);
  Serial.println("lastKeyPressTime: ");
  Serial.println(lastKeyPressTime);
  Serial.println("singleDigitEntered: ");
  Serial.println(singleDigitEntered);
  Serial.println("select a: ");
  Serial.println(select);
  }
       lcd.clear();
       lcd.setCursor(0, 0);
       lcd.print(knumber);
       delay(500);
       select = knumber -1;
       knumber = 0;

}
else {
  if (knumber > (max * maxrow))
  {
if (debug) {
    Serial.println("keypad entry invalid ");
    }
    lcd.clear();
    lcd.setCursor(0, 0);
    lcd.print(knumber);
    lcd.setCursor(0, 1);
    lcd.print("ungueltig!");
    digitalWrite(buzzer_pin, HIGH); 
    delay(500);
    digitalWrite(buzzer_pin, LOW); 
    knumber = 0;
 }
}
 
  // ********** BUTTON PRESSED **********

   
   for (int index = 0; index < max; index++) {    
    if 
     (((digitalRead(selector[index]) == LOW) and (!keypad)) or ((select == index) and (keypad)))
  
          { // button pressed
if (debug) {
      Serial.print("Spalte ");
      Serial.print(index + 1);
      Serial.println(" gedrueckt ");
      Serial.println(" items: ");
      Serial.print(conveyorItems[index]);
      Serial.println("  ");
      Serial.println(" INDEX selected:");
      Serial.println(select);
}      
      if (conveyorItems[index] > 0) {
        if (coinsCurrentValue < conveyorPrice[index]) { // insufficient balance - display price
          displayPrice(conveyorPrice[index]);
          idleTimerMillis = millis();
          delay(2000);
        }
       // #### SELL ITEM ##### 
        if ((coinsCurrentValue > conveyorPrice[index] - 1) ) { // sufficient balance
          coinsCurrentValue = coinsCurrentValue - conveyorPrice[index]; // reduce balance
          conveyorItems[index]--; // reduce items
    if (debug) {
    Serial.print("update EEPROM conveyorItem ");
    Serial.print(index * 2 + 4, conveyorItems[index]);          
    }
          writeEPROM (index * 2 + 4, conveyorItems[index]);
          if (coinsCurrentValue < 0) {
            coinsCurrentValue = 0;  // correct float rounding error
          }
          delay(200);
      
//          which compartment to open?
if (debug) {
    Serial.print("conveyorItems[index] ");
    Serial.print(conveyorItems[index]);
    Serial.print("index ");
    Serial.print(index);
    }
          if ( conveyorItems[index] == 0) {
           if (debug) {
          Serial.print("index open ");
           }
           CompartementOpen(index); }   
          if ( conveyorItems[index] == 1) {
          if (debug) {
          Serial.print("index plus max öffnen ");
          }          
          CompartementOpen(index + max); }
          if ( conveyorItems[index] == 2) {
           if (debug) {
          Serial.print("index + 2 * max ");
           }
          CompartementOpen(index + max + max); }
          displayBalance(); // display current balance
          idleTimerMillis = millis(); // reset idle timer

// turn off payment (coin acceptor or cashless system - ox ) if no further product available
// 

//          inform homematic about sold item only if serial.print not used (using digital pin1 which is dedicaded to serial) (issue with uno only)
          delay(100);
          digitalWrite(homematic_pin, LOW); 
          delay(1500);
          digitalWrite(homematic_pin, HIGH); 
          delay(200);
// inform Nayax Onyx about sold items but only if it was paid cash (possible last_paytype = O (onyx), N (nv10) or C (cash) )
  if (debug) {
    Serial.println("lastPaytype - C=Coin, N=NV10, O=Onyx, ?=not set: ");
    Serial.print(last_paytype);
    Serial.println("<-lastPaytype");
   }    


         if(ox) {
          if  (last_paytype != 'O') {
          ox_pulse_back (conveyorPrice[index]);
          } // not for ox payments
          } 


        }
        // ##### END SELL ITEM ##########
      } else {
        displayEmpty();
        idleTimerMillis = millis(); // reset idle timer
        delay(200);
      }
       //reset key 
       select = 999;
       knumber = 0;
    }
    
  }

//##### check if SMS incoming....
if (sim)
{

updateSerial(0);
}


}

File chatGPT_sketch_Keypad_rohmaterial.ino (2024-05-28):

#include <Wire.h>       // Standardbibliothek für I2C
#include <Keypad.h>     // Bibliothek für das Keypad
#include <Keypad_I2C.h> // Bibliothek für das Keypad über I2C

const byte ROWS = 4; // Vier Reihen
const byte COLS = 3; // Drei Spalten

char keys[ROWS][COLS] = {
  {'1','2','3'},
  {'4','5','6'},
  {'7','8','9'},
  {'*','0','#'}
};

byte rowPins[ROWS] = {0, 1, 2, 3}; // Verbindungen zu den Zeilen des Keypads (PCF8574 P0-P3)
byte colPins[COLS] = {4, 5, 6};    // Verbindungen zu den Spalten des Keypads (PCF8574 P4-P6)

Keypad_I2C customKeypad(makeKeymap(keys), rowPins, colPins, ROWS, COLS, 0x20); // 0x20 ist die I2C Adresse des PCF8574

unsigned long lastKeyPressTime = 0;
int number = 0;
bool singleDigitEntered = false;

void setup() {
  Serial.begin(9600);
  Wire.begin();
  customKeypad.begin();
}

void loop() {
  char key = customKeypad.getKey();

  if (key) {
    unsigned long currentTime = millis();

    if (singleDigitEntered && (currentTime - lastKeyPressTime <= 1000)) {
      // Zweite Taste innerhalb einer Sekunde gedrückt
      number = number * 10 + (key - '0');
      singleDigitEntered = false;
      Serial.println(number);
    } else {
      // Erste Taste gedrückt
      number = key - '0';
      singleDigitEntered = true;
      lastKeyPressTime = currentTime;
    }
  }

  // Überprüfen, ob mehr als eine Sekunde seit der letzten Eingabe vergangen ist
  if (singleDigitEntered && (millis() - lastKeyPressTime > 1000)) {
    singleDigitEntered = false;
    Serial.println(number);
  }
}

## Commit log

2022-01-26 10 vendor compartments arduino uno V3
    5 or 10 compartments
2022-01-26 honey vendor machine 10 compartments arduino uno
    [PIN_assignment_arduino.xlsx]
2022-02-19 release 2 uno v3 and mega2560
    feature with release 2:
    - number of rows and columns (rows * columns = total number of compartments) can be configured
    - sketches for Mega and Uno
    - store data (available products & prices in EEPROM)
    - poweroff possible to save enery (acco mode)
    - delete credit after cutoff time
    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
    [Honigautomat_megaPowersave.fzz, Honigautomat_unoPowersave.fzz, PIN_assignment_arduino.xlsx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]
2022-02-22 Update honig_uno_10comp.ino
    pin assigned changed from mega to uno specific
2022-02-27 Update honig_Mega2560.ino
    PowerOff feature deactivated for Mega (row 61: powersave = 0;)
2022-03-31 setting for Powersafe changed and some fixes for Mega-sketch
    [Honigautomat_megaPowersave.fzz, PIN_assignment_arduino.xlsx]
2022-05-01 Create honig_uno_5comp.ino
    UNO 5 compartments, Power-Off after 2 1/2 minutes (can be deactivated)
2022-05-24 powersave corrected
    corrected powersave function for both types, uno and mega
    [Honigautomat_megaPowersave.fzz, Honigautomat_unoPowersave.fzz, PIN_assignment_arduino.xlsx]
2022-06-02 effort estimation
    now effort estimation (time) and money (material)
    [Aufwandschätzung.xlsx, Teileliste_neu20220131.xlsx]
2022-06-12 optimised coin counting interval
    extended intervall (from 135ms to 140 ms) to support newer coin counter hardware. New effort estimations.
    [Aufwandschätzung.xlsx]
2022-10-25 parts list and support files changed
    [Teileliste_neu20220131.xlsx, Teileliste_neu20220922.xlsx]
2023-01-27 coin acceptor can be disabled; bill payement ; kreditcards
    it is now possible to disable the coin acceptor when all products are sold out.
    Payment with bill (Geldscheinleser) NV10 now possible.
    Cashless payment (e.g. Creditcard, Debitcard, Applepay ...) now supported
    [PIN_assignment_arduino.xlsx, Teileliste_neu20220922.xlsx]
2023-01-27 coin acceptor can be disabled; bill payment, credit cards
    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
    [PIN_assignment_arduino.xlsx, Teileliste_neu20220922.xlsx]
2023-06-01 r3 bill payment and cooling
    bill payment for Mega
    cooling with DS18B20 for UNO
    [PIN_assignment_arduino.xlsx]
2023-06-07 Revert "Merge branch 'main' of https://github.com/matgrhn/honigautomat"
    This reverts commit 5830dfdff19be9e6b2ad839832d81a4e94c98684, reversing
    changes made to 5e11ea68bec77137a8a4cc21740d7d277648e682.
    [PIN_assignment_arduino.xlsx]
2023-06-08 NV10 false pulses issue solved
    NV10 Dip2 on high: 4 pulses instead of 1 helps to solve issues with false pulses (impact when opening compartments). single pulses are now ignored
    [honig_Mega2560.ino]
2024-01-01 PowerBoard
    Circuit board design for power supply board sketch (including LM2596 12V->5V)
2024-01-02 Update Power_Board.pdf
    corrected power board
2024-04-04 SIM800L SMS & Paypal
    now possible to send and receive SMS, can be used to configure threshold (receive) on which number of remaining products sms to be send. In addition to load money onto the system and payment with Pay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
    [Aufwandschätzung.xlsx, PIN_assignment_arduino.xlsx]
2024-04-11 cash payments now reported via onyx
    feed back cash payment to nayax using same pin for both directions (receive pulse for credit card payments or send back pulse for cash payments.
    refill can be started via SMS, send "refill".
2024-05-26 part list with updated links
    [Teileliste.xlsx, Teileliste_neu20220922.xlsx]
2024-05-26 updated parts list
    including some pictures in case of links not working any more
    [Teileliste.xlsx]
2024-05-28 Keypad I2C-Expander - sketch generated by ChatGPT
    basis source to use key pad to enter two digit numbers using I2C and bus expander PCF8547. Later this will be included in honigautomat sketch für arduino Mega
2024-06-22 fix Paypal SMS
    some SMS have a different format than others, containing one or two spaces before text "EUR". Both is now considered.
    [chatGPT_sketch_Keypad_rohmaterial.ino, honig_Mega2560_SMS.ino]
2024-10-01 Paypal sms text corrected
    [honig_Mega2560_SMS.ino]
2024-10-10 4.0 keypad
    4.0 keypad
    [Honigautomat_unoPowersave.fzz, PIN_assignment_arduino.xlsx]
2024-10-13 keypad = false; -> default is button
    set ist to true if you want to use the keypad and not the buttons.
2024-10-15 revised sms process concerning threshold
    in case of threshold=3 sms will be send when remaining products are 3 and 0 (not 3>2>1>0 any more); after refill no further sms will be provided.
2024-10-28 docu about compile issues improved
    [honig_Mega2560_keypad.ino]
2024-12-07 decimal values with Paypal corrected
    Fixed an error when calculating decimal values with Paypal
    [Teileliste.xlsx]
2025-02-03 issue with nv10 interrupt solved
    [honig_Mega2560_keypad.ino]
